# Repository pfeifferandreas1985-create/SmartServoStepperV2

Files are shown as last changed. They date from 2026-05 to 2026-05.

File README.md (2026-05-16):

# 🦾 SmartServoStepperV2

A high-performance Smart Stepper Servo based on the ESP32-C3 Super Mini, TMC2209 driver, and AS5600 magnetic encoder.

## 🚀 Key Features (v3.0.0 Stable)
- **Direct Frequency Positioning:** Oscillation-free, ultra-precise CNC-style open-loop positioning via `FastAccelStepper`.
- **Dual Communication:** Hybrid WiFi (FritzBox Station Mode + Fallback Access Point).
- **Web Dashboard:** Interactive HTML/JS GUI with real-time telemetry (RPS, Angle).
- **Hybrid TMC2209 Control:** Hardware timers for perfect Step/Dir movement, paired with UART for smart driver configuration (SpreadCycle, current limits).

## 📌 Hardware Configuration
| Component | ESP32-C3 GPIO | Function |
| :--- | :--- | :--- |
| UART RX | 5 | Data from TMC2209 |
| UART TX | 6 | Data to TMC2209 |
| ENABLE | 3 | Driver Stage Control |
| STEP | 4 | Hardware Timer Steps |
| DIR | 2 | Hardware Timer Direction |
| I2C SDA | 0 | AS5600 Data |
| I2C SCL | 10 | AS5600 Clock |
| Status LED| 8 | System Heartbeat |

## 📦 Software Setup
1. **Arduino IDE Settings:**
   - Board: `ESP32C3 Dev Module`
   - USB CDC On Boot: **ENABLED** (Required for Serial Monitor)
   - Flash Mode: **DIO**
2. **Libraries Required:**
   - `TMCStepper`
   - `FastAccelStepper`
   - `ArduinoJson (v7)`
   - `WebSocketsServer`
   - `AS5600`
3. **Usage:**
   - Upload `SmartServoStepperV2.ino`.
   - Access the dashboard at `192.168.178.78` (FritzBox) or `192.168.4.1` (AP).

## 🛠 Stability Fixes
- **Startup Delay:** A 3-second delay in `setup()` ensures the USB-CDC port enumerates correctly.
- **Pin Mapping:** Re-routed signals away from sensitive strap pins (GPIO 9) to ensure reliable boots.
- **Encoder Filtering:** 20ms RPS window to prevent aliasing at high speeds.

---
*Maintained by pfeifferandreas1985*

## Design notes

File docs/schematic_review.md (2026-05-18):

# Hardware-Review: Smart Servo Stepper V2 Schaltplan (Phase 2)

**Review-Datum:** 18. Mai 2026  
**Geprüfte Datei:** `/home/ubuntu/Dokumente/output.pdf`  
**Status:** **Teilweise korrigiert – Nahezu produktionsbereit!**

---

## 1. Zusammenfassung der Änderungen (Was wurde korrigiert?)

Der aktualisierte Schaltplan wurde erfolgreich geprüft. Sie haben die kritischsten Stabilitätsprobleme hervorragend gelöst:

*   **TMC Enable Boot-Schutz (Erfolgreich gelöst):** `TMC_EN` (GPIO 3) wird jetzt über den **10 kΩ Widerstand R3** sauber gegen 3.3V gezogen. Der Motor bleibt beim Booten und Flashen absolut still.
*   **Split-UART Schutzwiderstand (Erfolgreich gelöst):** Der **1 kΩ Schutzwiderstand R5** wurde vom RX-Pfad in den TX-Pfad (`TMC_TX` an GPIO 6) verschoben. Damit ist die Kurzschlussgefahr bei Bus-Kollisionen vollständig gebannt!
*   **Symmetrische I2C Pull-Ups (Erfolgreich gelöst):** Sowohl `I2C_SDA` als auch `I2C_SCL` werden jetzt über symmetrische **4.7 kΩ Widerstände** (R2 und R1) versorgt. Das sorgt für saubere Flanken bei 400 kHz (I2C Fast Mode).

---

## 2. Antworten auf Ihre Fragen

### Frage 1: Soll ich SDA von GPIO 0 auf GPIO 20 legen?
> [!IMPORTANT]
> **Ja, absolut!** GPIO 0 ist ein sogenannter **Boot-Strapping-Pin**. Liegt SDA auf GPIO 0 und zieht der AS5600-Encoder die Leitung beim Einschalten auf GND, bootet der ESP32-C3 nicht mehr in Ihre Firmware, sondern bleibt im Download-Modus hängen. 
> 
> Wenn Sie **SDA auf GPIO 20** legen, ist Ihr I2C-Bus wie folgt verdrahtet:
> *   **I2C_SDA:** GPIO 20 (Pin 15) mit 4.7 kΩ Pull-Up gegen 3.3V.
> *   **I2C_SCL:** GPIO 10 (Pin 14) mit 4.7 kΩ Pull-Up gegen 3.3V.
> *   **GPIO 0:** Bleibt komplett unbeschaltet (perfekt für einen sicheren Boot-Vorgang).
> 
> *Hinweis:* Im offiziellen V1.7-Standard des Repositories ist es genau umgekehrt definiert (SDA = GPIO 10, SCL = GPIO 20). Da der ESP32-C3 die Pins jedoch völlig frei konfigurieren kann, ist Ihre Kombination (**SDA = GPIO 20, SCL = GPIO 10**) **technisch absolut gleichwertig und 100% sicher!**

---

### Frage 4: Muss DIAG angeschlossen sein oder kann man diese Funktionen über UART nutzen?
*   **Ja, man kann die StallGuard-Werte (Lasterkennung) über UART auslesen:** Der TMC2209 aktualisiert kontinuierlich das Register `SG_RESULT` (Wert `0` = Blockade). Ihre Firmware kann diesen Wert zyklisch über UART abfragen.
*   **Warum Sie DIAG trotzdem anschließen sollten (Empfehlung):**
    1.  **Latenz (Verzögerung):** Eine UART-Abfrage dauert ca. 1–2 Millisekunden. In dieser Zeit dreht der blockierte Motor weiter und rattert lautstark. Der `DIAG`-Pin ist ein **Hardware-Interrupt**. Er schaltet im selben Mikrosekundenbruchteil auf HIGH, in dem die Blockade auftritt. Der ESP32 kann dadurch sofort stoppen.
    2.  **Bibliotheks-Support:** Fast alle bekannten Bibliotheken (wie `TMCStepper`) nutzen den DIAG-Pin als externen Interrupt für das sensorlose Referenzieren (Sensorless Homing).
*   **Wann Sie DIAG weglassen können:**
    *   Da Sie den **AS5600 Magnet-Encoder** für echtes **Closed-Loop-Control** verbaut haben, benötigen Sie StallGuard für die Positionskontrolle meist gar nicht! Der Encoder erkennt ohnehin sofort jede Abweichung zwischen Soll- und Ist-Position. Wenn Sie kein sensorloses Homing verwenden, sondern normale Endschalter (oder rein über den Encoder referenzieren), kann der DIAG-Pin **problemlos unbeschaltet bleiben**.

---

## 3. Letzte verbleibende Detail-Empfehlungen (Feinschliff)

Falls Sie sich entscheiden, den **DIAG-Pin** für maximale Flexibilität doch anzuschließen, können Sie ein geniales Pin-Mapping-Dominospiel nutzen, das gleichzeitig Pins spart:

```
┌────────────────────────────────────────────────────────┐
│ UART-Pins zusammenführen (Single-Wire)                  │
│ ESP32 GPIO 6 ──► [ 1kΩ Schutz ] ──┬──► TMC2209 PDN     │
│                                   └──► 4.7kΩ Pull-Up   │
└────────────────────────────────────────────────────────┘
```

1.  **UART auf einen Pin reduzieren:** Da der ESP32-C3 hardwareseitig echten Eindraht-UART (Half-Duplex) unterstützt, können Sie `TMC_TX` und `TMC_RX` auf dem ESP32-Pin **GPIO 6** zusammenführen (über den 1 kΩ Serienwiderstand).
2.  **GPIO 5 freigeben:** Dadurch wird **GPIO 5** (der bisherige `TMC_RX`) frei!
3.  **TMC_DIR verschieben:** Legen Sie `TMC_DIR` von GPIO 2 auf den frei gewordenen **GPIO 5** (entspricht exakt der V1.7 Spezifikation).
4.  **GPIO 2 für DIAG nutzen:** Nun ist **GPIO 2** frei und Sie können den `DIAG`-Pin des TMC2209 dorthin verkabeln (mit einem 4.7 kΩ Pull-Up gegen 3.3V).

Mit diesem Kniff haben Sie **DIAG voll funktionsfähig angeschlossen**, ohne einen einzigen zusätzlichen Pin des ESP32-C3 Super Mini zu verschwenden!

---

## 4. Fazit der Freigabe

*   Wenn Sie **SDA auf GPIO 20** verschieben und die DIAG-Funktion nicht zwingend über einen Hardware-Interrupt benötigen: **Der Schaltplan ist hiermit FREIGEGEBEN für das PCB-Layout!**
*   Wenn Sie die DIAG-Interrupt-Funktion nutzen möchten: Setzen Sie das unter Abschnitt 3 beschriebene Pin-Dominospiel um. Danach ist der Plan ebenfalls **FREIGEGEBEN**.

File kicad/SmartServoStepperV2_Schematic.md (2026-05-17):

# SmartServoStepperV2 – Konsistenter KiCad-Stromlaufplan

**für ESP32-C3 Super Mini + TMC2209 Tenstar Robot V2 + AS5600**

> Verifiziert gegen Firmware `SmartServoStepperV2.ino` (Stand: Mai 2026)

---

## 1. Power Architecture

### VMOT Eingang (12–24V)

```text
VIN_MOTOR ────────────────+─────────────> VMOT (TMC2209)
                          |
                          |
                       [SMBJ24A]
                          |
                         GND

VIN_MOTOR ──────+────────────+
                |            |
              [470µF]      [100nF]
                |            |
               GND          GND
```

### Buck Converter (MP1584EN)

```text
VIN_MOTOR ─────────> MP1584EN IN+

GND ───────────────> MP1584EN IN-

MP1584 OUT+ ───────> +5V_SYS
MP1584 OUT- ───────> GND
```

### 5V Ausgangspufferung

```text
+5V_SYS ──────+────────+────────+
              |        |        |
            [100µF] [47µF] [100nF]
              |        |        |
             GND      GND      GND
```

---

## 2. ESP32-C3 Super Mini Versorgung

```text
+5V_SYS ─────────────> ESP32 5V
GND ─────────────────> ESP32 GND
```

---

## 3. 3.3V Logic Rail

```text
ESP32 3V3 ───────────> +3V3_LOGIC
```

**Verbraucher:**
- AS5600 VCC
- TMC2209 VIO
- I2C Pullups
- UART Pullup
- ENABLE Pullup

---

## 4. AS5600 Encoder

### Versorgung

```text
+3V3_LOGIC ───────> AS5600 VCC
GND ──────────────> AS5600 GND

+3V3_LOGIC ──[10µF]── GND
```

### I2C

```text
ESP32 GPIO0  ─────────────> SDA
                     |
                   [4.7k]
                     |
                  +3V3

ESP32 GPIO10 ────────────> SCL
                     |
                   [4.7k]
                     |
                  +3V3
```

---

## 5. TMC2209 Tenstar V2

### Versorgung

```text
VMOT  ─────────────> VM
GND   ─────────────> GND

+3V3_LOGIC ────────> VIO
```

### STEP / DIR

```text
ESP32 GPIO4 ───────> STEP

ESP32 GPIO2 ───────> DIR
```

### ENABLE (Boot-Safe)

```text
ESP32 GPIO3 ───────> EN

EN ─────[10k]──────> +3V3
```

> Damit bleibt der Treiber beim Boot deaktiviert.

---

## 6. UART Verbindung (WICHTIG)

Beim Tenstar TMC2209 V2 wird UART über PDN_UART geführt.

### Verschaltung

```text
ESP32 GPIO5 (RX) ───────────────┐
                                │
                                ├────> PDN_UART
                                │
ESP32 GPIO6 (TX) ──[1k]─────────┘

PDN_UART ──[4.7k]──> +3V3
```

> **Hinweis:** Der 1kΩ Serienwiderstand sitzt am **TX-Pin (GPIO 6)**, damit bei der Two-Wire-Konfiguration der TMC2209 den Bus beim Antworten übersteuern kann.

---

## 7. Feetech Half-Duplex Bus (1 Mbps)

**Verwendet:**
- GPIO1 = TX
- GPIO7 = RX
- BSS138 Bidirectional Level Shifter

---

## 8. Level Shifter Verschaltung

### LV-Seite (3.3V)

```text
ESP32 GPIO1 ──[220R]──> LV1

ESP32 GPIO7 ──────────> LV2

LV ───────────────────> +3V3
GND ──────────────────> GND
```

### HV-Seite (5V)

```text
HV1 ───────┐
           ├──────> FEETECH_DATA
HV2 ───────┘

HV ────────────────> +5V_SYS

FEETECH_DATA ──[2.2k]──> +5V_SYS
```

---

## 9. Motoranschlüsse

```text
TMC2209 A1 ─────> MOTOR_A+
TMC2209 A2 ─────> MOTOR_A-

TMC2209 B1 ─────> MOTOR_B+
TMC2209 B2 ─────> MOTOR_B-
```

---

## 10. USB / JTAG

```text
GPIO18 → NC
GPIO19 → NC
```

> **Nicht verbinden.**

---

## 11. Empfohlene KiCad-Netlabels

### Power

| Label | Beschreibung |
| :--- | :--- |
| `VIN_MOTOR` | Eingangsversorgung 12–24V |
| `+5V_SYS` | Buck-Converter Ausgang |
| `+3V3_LOGIC` | ESP32 3.3V Rail |
| `GND` | Masse |
| `VMOT` | TMC2209 Motor-Versorgung |

### Motor

| Label | Beschreibung |
| :--- | :--- |
| `MOTOR_A+` | Spule A+ |
| `MOTOR_A-` | Spule A- |
| `MOTOR_B+` | Spule B+ |
| `MOTOR_B-` | Spule B- |

### I2C

| Label | Beschreibung |
| :--- | :--- |
| `I2C_SDA` | GPIO0 |
| `I2C_SCL` | GPIO10 |

### TMC

| Label | Beschreibung |
| :--- | :--- |
| `TMC_STEP` | GPIO4 |
| `TMC_DIR` | GPIO2 |
| `TMC_EN` | GPIO3 |
| `TMC_UART` | PDN_UART (GPIO5 + GPIO6) |

### Feetech

| Label | Beschreibung |
| :--- | :--- |
| `FEETECH_TX` | GPIO1 |
| `FEETECH_RX` | GPIO7 |
| `FEETECH_DATA` | 5V Bus (1-Wire) |

---

## 12. Kritische Layoutregeln

### TMC2209

- 470µF Elko **maximal 15 mm** vom VM-Pin entfernt
- Breite VMOT-Polygonfläche
- **Thermal-Vias** unter Exposed Pad:
  - Mindestens **5 Stück**
  - **0.3 mm** Drill
  - Via-in-pad optional

### I2C

- SDA/SCL **kurz** halten
- **Nicht** parallel zu Motorphasen

### UART

- PDN_UART **kurz** routen
- **Keine** Nähe zu STEP-Leitung

### Motorphasen

- A/B **differenziell und symmetrisch**
- Möglichst **breite Leiterbahnen**

---

## 13. ERC-kritische Hinweise

> **WICHTIG:** Der ESP32-C3 besitzt einige Boot-Strapping-Pins.

Die gewählte Belegung ist gültig, weil:

- **GPIO3** durch Pull-Up definiert
- **GPIO0** nur via I2C Pull-Up belastet
- **GPIO1** TX nur über 220R gekoppelt
- **GPIO18/19** unbenutzt

**Damit ist das Design bootfähig.**

---

## 14. Empfohlene KiCad-Hierarchie

```text
ROOT
├── Power.kicad_sch
├── ESP32.kicad_sch
├── TMC2209.kicad_sch
├── AS5600.kicad_sch
├── FeetechBus.kicad_sch
└── Connectors.kicad_sch
```

---

## 15. Footprint-Empfehlungen

### Passiv

| Typ | Footprint |
| :--- | :--- |
| 100nF | 0603 |
| 4.7kΩ | 0603 |
| 220Ω | 0603 |
| 1kΩ | 0603 |
| 2.2kΩ | 0603 |
| 10kΩ | 0603 |
| 10µF | 0805 |
| 47µF X7R | 1206 |
| 470µF Elko | Radial D10 |

---

## 16. Wichtigste elektrische Freigabe

Dieses Design ist konsistent bezüglich:

- ✅ Power Domains
- ✅ Boot-Verhalten
- ✅ UART (TMC2209 Two-Wire)
- ✅ I2C (AS5600)
- ✅ Half-Duplex Bus (Feetech via BSS138)
- ✅ ESP32-C3 Bootstrapping
- ✅ 3.3V / 5V Pegel
- ✅ EMV-Basismaßnahmen

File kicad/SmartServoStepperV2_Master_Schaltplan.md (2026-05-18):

# SmartServoStepperV2 – PCB Wiring & Schaltplan (v2.2 Verified)

Dieses Dokument ist der **Master-Bauplan** für das PCB-Layout, optimiert für den Einsatz von fertigen Modulen (ESP32-C3 Super Mini + Tenstar TMC2209 V2) und externen Anschlüssen über Dupont-Steckverbinder.

---

## 1. Systemarchitektur & Power Grid

### VMOT (12V–24V) – Haupteinspeisung über Stecker [J1]

- **Quelle:** Pin 1 von Stecker J1 (3-pol. Dupont).
- **Schutz:** SMBJ24A TVS-Diode (transiente Überspannungen) + 100nF Keramik (HF-Filter) direkt hinter dem Stecker-Pin gegen GND.
- **Pufferung:** 470 µF / 50V Elko (Low-ESR) unmittelbar an den VM / GND Pins der Tenstar-Modul-Stiftleiste.

### 5V System (SYS) – Logik-Hauptstromkreis

- **Quelle:** MP1584EN Buck-Converter (Ausgang lokal gepuffert mit 22µF Keramik).
- **MCU-Pufferung:** 100 µF Elko + 47 µF Keramik (X7R, 1206) + 100 nF Keramik parallel geschaltet, so nah wie möglich am 5V-Pin des ESP32-C3 Super Mini Moduls.
- **Bus-Speisung:** Dient als Pull-Up-Quelle für die 5V-Busseite (1-Wire TTL).

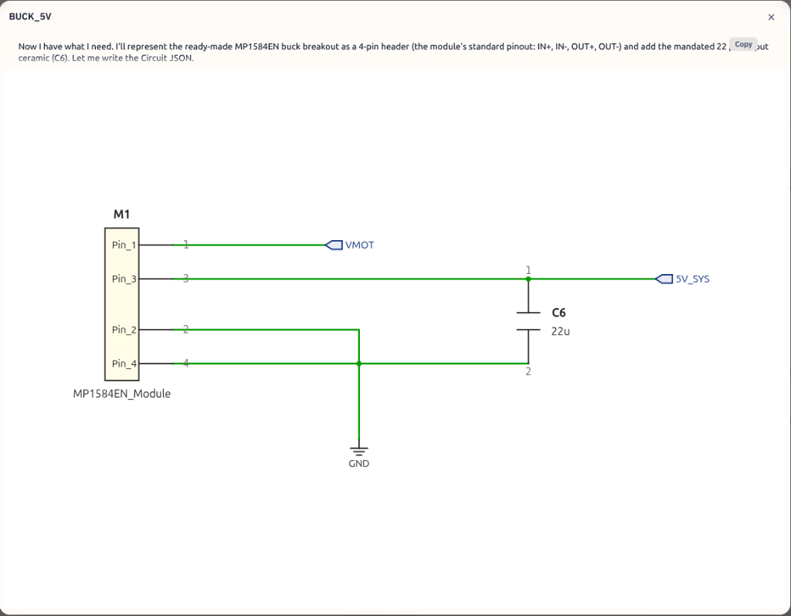
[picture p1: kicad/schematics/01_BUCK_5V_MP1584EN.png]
MP1584EN Buck Converter 5V Schaltplan


### 3.3V Logik (LOGIC) – Signalstromkreis

- **Quelle:** Interner Spannungsregler des ESP32-C3 Super Mini (wird am 3V3-Pin des Moduls abgegriffen).
- **TMC2209 VIO:** Zwingend mit dieser 3.3V-Schiene verbinden.
- **Sensor-Speisung:** Wird direkt an Pin 1 des AS5600-Steckers J2 geführt.

---

## 2. Externe Steckverbinder (Interfaces)

### J1: Hauptanschluss (3-poliger Dupont-Stecker)

Dieser Stecker führt die Spannungsversorgung zu und bindet die Platine an den externen Feetech 1-Wire TTL Bus an.

| Pin | Signal | Beschreibung |
| :--- | :--- | :--- |
| **Pin 1** | `VMOT` | 12V–24V Eingang |
| **Pin 2** | `GND` | Gemeinsame Systemmasse |
| **Pin 3** | `FT_DATA` | 5V 1-Wire TTL Busleitung |

### J2: AS5600 Encoder-Anschluss (4-poliger Dupont-Stecker)

Über diesen Stecker wird das extern sitzende AS5600-Sensor-Modul ausgelesen.

| Pin | Signal | Beschreibung |
| :--- | :--- | :--- |
| **Pin 1** | `3V3_LOGIC` | Spannungsversorgung für den Sensor |
| **Pin 2** | `GND` | Masse |
| **Pin 3** | `I2C_SDA` | I2C Datenleitung, mit 4.7kΩ Pull-Up auf dem Mainboard |
| **Pin 4** | `I2C_SCL` | I2C Taktleitung, mit 4.7kΩ Pull-Up auf dem Mainboard |

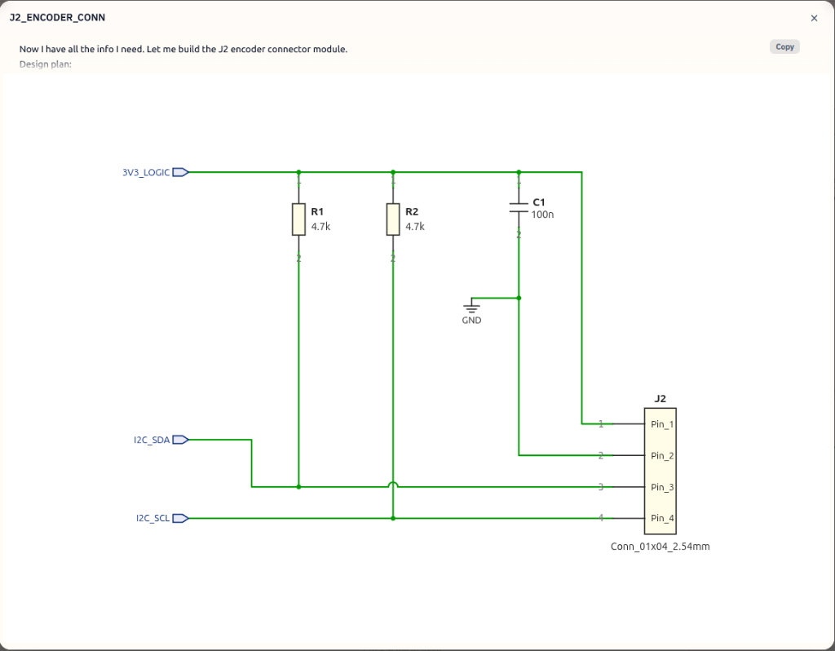
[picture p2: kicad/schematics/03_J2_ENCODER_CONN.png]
J2 Encoder Connector Schaltplan


---

## 3. Finales Pin-Mapping (ESP32-C3 Super Mini Modul)

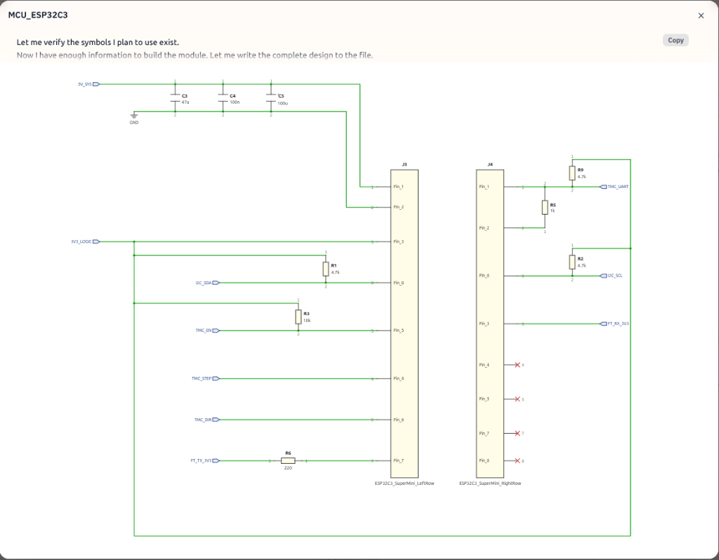
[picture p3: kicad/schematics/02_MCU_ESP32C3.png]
MCU ESP32-C3 Super Mini Schaltplan


| Modul Pin | Funktion | Beschreibung | Hardware-Beschaltung auf dem Mainboard |
| :--- | :--- | :--- | :--- |
| **5V** | `5V_SYS` | Moduleingang 5V | MP1584EN Ausgang / Bulk-Kondensatoren (C3, C4, C5) |
| **3V3** | `3V3_LOGIC` | Modulausgang 3.3V | Speist VIO (TMC), Stecker J2 Pin 1, Level Shifter & Pull-Ups |
| **GND** | `GND` | Systemmasse | Verbunden mit der zentralen Massefläche (Ground Plane) |
| **GPIO 0** | *Unbeschaltet* | Boot-Strap-Pin | **Zwingend offen lassen**, um Boot-Konflikte der MCU zu verhindern! |
| **GPIO 1** | `FT_TX` | Bus Senden | Über R6 (220Ω) Serienwiderstand → BSS138 Source 1 |
| **GPIO 2** | `TMC_DIR` | Richtungs-Signal | Direkt an Tenstar TMC2209 Pin: DIR |
| **GPIO 3** | `TMC_EN` | TMC2209 EN (Active LOW) | R3 (10kΩ) Pull-UP gegen 3V3_LOGIC → Tenstar Pin: EN |
| **GPIO 4** | `TMC_STEP` | Schritt-Impuls | Direkt an Tenstar TMC2209 Pin: STEP |
| **GPIO 5** | `TMC_RX` | UART Rx | Direkt an Netzknoten TMC_UART_NODE |
| **GPIO 6** | `TMC_TX` | UART Tx | R5 (1kΩ) Schutzwiderstand in Serie zu TMC_UART_NODE |
| **GPIO 7** | `FT_RX` | Bus Empfangen | Direkt → BSS138 Source 2 |
| **GPIO 8** | Status-LED | On-Board LED (Blau) | Modulintern verschaltet (Active LOW) |
| **GPIO 10** | `I2C_SCL` | I2C Takt (AS5600) | R2 (4.7kΩ) Pull-UP gegen 3V3_LOGIC → Stecker J2 Pin 4 |
| **GPIO 18** | USB D- | Intern reserviert | **Physisch unbeschaltet lassen!** (Verhindert USB-JTAG Störungen) |
| **GPIO 19** | USB D+ | Intern reserviert | **Physisch unbeschaltet lassen!** (Verhindert USB-JTAG Störungen) |
| **GPIO 20** | `I2C_SDA` | I2C Daten (AS5600) | R1 (4.7kΩ) Pull-UP gegen 3V3_LOGIC → Stecker J2 Pin 3 |

---

## 4. Spezifische Schaltungsdetails

### 4.1 Feetech-Bus High-Speed Level Shifter (3.3V ↔ 5V Eindraht)

Die TX/RX-Pfade des ESP32 werden zusammengeführt und auf die 5V-Ebene angehoben, um am Stecker J1 als echtes Eindraht-TTL-Signal anzuliegen.

```text
ESP32-C3 Modul Pins                                       Hauptstecker J1
───────────────────                                       ───────────────
GPIO 1 (TX) ──→ [ R6: 220Ω ] ──→ BSS138 (Source 1) ──┐
                                                     ├───► Pin 3: DATA (1-Wire)
GPIO 7 (RX) ───────────────────→ BSS138 (Source 2) ──┘
                                                     │
                                               [ R8: 2.2kΩ Pull-Up ] → 5V_SYS
```

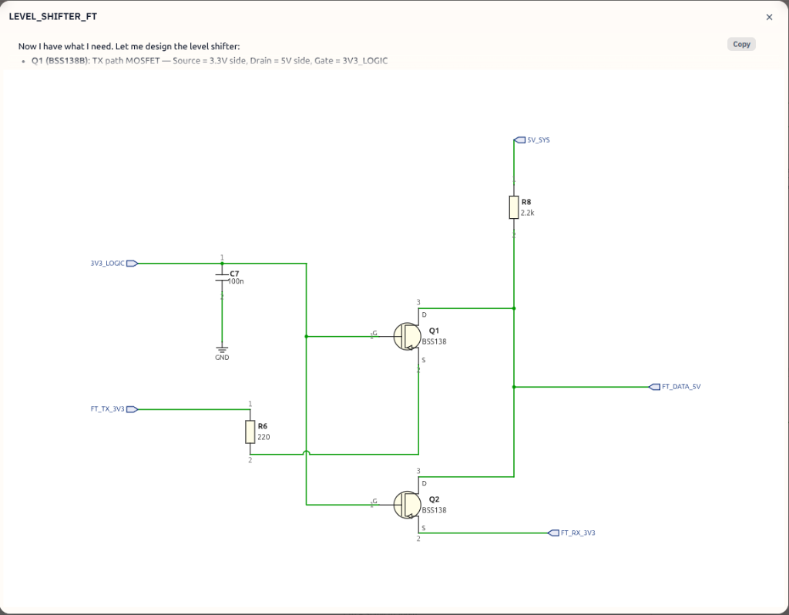
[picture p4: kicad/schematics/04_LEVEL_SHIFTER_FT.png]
Feetech-Bus Level Shifter Schaltplan


### 4.2 TMC2209 UART (Two-Wire to One-Wire Konfiguration)

```text
ESP32-C3 GPIO 5 (RX) ───────────────────────────┬───► [ Tenstar Modul Pin: PDN_UART ]
                                                │
ESP32-C3 GPIO 6 (TX) ─── [ R5: 1 kΩ Serie ] ────┤
                                                │
3V3_LOGIC ────────────── [ R9: 4.7 kΩ Pull-Up ] ┘
```

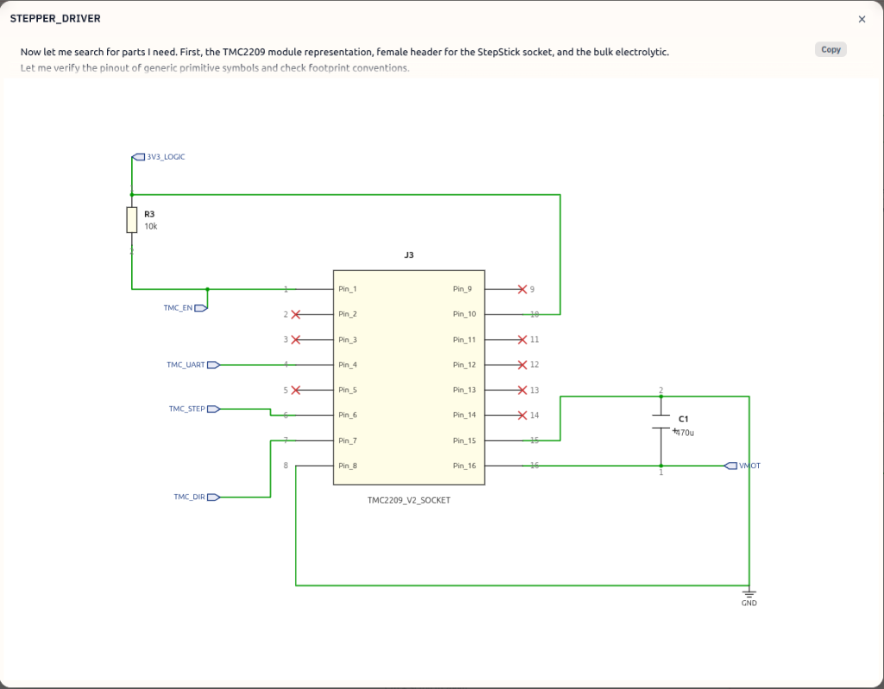
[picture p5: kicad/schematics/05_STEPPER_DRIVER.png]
Stepper Driver TMC2209 Schaltplan


---

## 5. Stückliste (BOM)

### Aktive Bauteile & Module

| Typ | Bauteil / Modul | Menge | Funktion |
| :--- | :--- | :--- | :--- |
| **MCU** | ESP32-C3 Super Mini Modul | 1x | Hauptprozessor |
| **Driver** | Tenstar TMC2209 V2 Modul | 1x | Schrittmotortreiber (StepStick) |
| **Comms** | BSS138 Transistor / Modul | 2x / 1x | Pegelwandler für den Feetech-Bus |
| **Power** | MP1584EN Buck Converter Modul | 1x | Step-Down-Regler (12V/24V → 5V) |
| **Schutz** | SMBJ24A TVS-Diode | 1x | Transientenschutz an der Stromeinspeisung |

### Passivbauteile & Verbinder

| ID | Bauteiltyp | Wert / Typ | Platzierung / Funktion |
| :--- | :--- | :--- | :--- |
| J1 | Dupont-Stiftleiste | 3-polig, gerade/gewinkelt | Hauptanschluss: 12V-24V IN / GND / 1-Wire DATA |
| J2 | Dupont-Stiftleiste | 4-polig, gerade/gewinkelt | Externer Encoder-Anschluss: 3V3 / GND / SDA / SCL |
| C1 | Elko (Low-ESR, ≥ 50V) | 470 µF | Direkt an den Pins VM / GND der Tenstar-Stiftleiste |
| C2 | Keramik-Kondensator | 100 nF | Direkt an Stecker J1 (Pin 1 / Pin 2) parallel zur TVS-Diode |
| C3 | Keramik (X7R, 1206) | 47 µF | Direkt am Pin 5V der ESP32-Stiftleiste |
| C4 | Keramik-Kondensator | 100 nF | Entkopplung, parallel zu C3 am ESP32 5V Pin |
| C5 | Elko (≥ 10V) | 100 µF | Bulk-Puffer, parallel zu C3/C4 am ESP32 5V Pin |
| C6 | Keramik-Kondensator | 22 µF | Direkt am Ausgang (OUT+) des MP1584EN Moduls |
| R1 | Widerstand | 4.7 kΩ | Pull-Up: I2C_SDA → 3V3_LOGIC (nahe Stecker J2) |
| R2 | Widerstand | 4.7 kΩ | Pull-Up: I2C_SCL → 3V3_LOGIC (nahe Stecker J2) |
| R3 | Widerstand | 10 kΩ | Boot-Safe Pull-Up: Tenstar Pin EN → 3V3_LOGIC |
| R5 | Widerstand | 1 kΩ | Schutzwiderstand: ESP32 GPIO 6 (TX) → TMC_UART_NODE |
| R6 | Widerstand | 220 Ω | Schutzwiderstand: ESP32 GPIO 1 (TX) → BSS138 Source 1 |
| R8 | Widerstand | 2.2 kΩ | Bus-Terminierung: J1 Pin 3 (DATA) → 5V_SYS |
| R9 | Widerstand | 4.7 kΩ | Bus-Pull-Up: TMC_UART_NODE → 3V3_LOGIC |

---

## 6. Layout-Hinweise für diese Revision

- **Leistungsführung (VMOT/GND):** Die Leiterbahn von J1 Pin 1 (VMOT) zu TMC2209 VM sowie von J1 Pin 2 (GND) zu TMC2209 GND muss die breiteste Verbindung auf der Platine sein, da hier der volle Motorstrom fließt (siehe Detailtabelle unten).

- **I2C-Leitungen schützen:** Die Leitungen von GPIO 20 und GPIO 10 zum Stecker J2 sollten parallel und nah beieinander geführt werden. Halte sie fern von den Motor-Ausgangsleitungen (Pins 1A, 1B, 2A, 2B des Treibers), um induktive Störungen auf dem I2C-Bus zu vermeiden.

- **Kondensatoren-Platzierung:** C3, C4, C5 gehören im Layout direkt an den 5V-Pin des ESP32-Moduls, nicht an den Ausgang des Buck-Converters. C1 gehört direkt an den VM-Pin des Treiber-Moduls.

---

## 7. Leiterplatten-Designregeln & Leiterbahnbreiten (IPC-2152)

Um eine minimale Erwärmung (max. ΔT = 10°C) bei einer standardmäßigen Kupferauflage von **35 µm (1 oz)** zu gewährleisten, müssen für das PCB-Layout in KiCad die folgenden **Netzklassen (Net Classes)** definiert und angewendet werden.

### 7.1 Spezifikation der Netzklassen für KiCad

| Netzklasse (KiCad Name) | Zugehörige Netze (Net Names) | Max. Strom | Empf. Breite (External) | Empf. Breite (Internal) | Clearance (Abstand) |
| :--- | :--- | :---: | :---: | :---: | :---: |
| **Power_High** | `+12V`, `/M1A`, `/M1B`, `/M2A`, `/M2B` | **2,5 A** | **1,0 mm** (~40 mil) | **1,5 mm** (~60 mil) | **0,3 mm** (~12 mil) |
| **Power_Medium** | `+5V`, `/5V` | **1,0 A** | **0,4 mm** (~16 mil) | **0,6 mm** (~24 mil) | **0,2 mm** (~8 mil) |
| **Power_Logic** | `+3.3V`, `+3V3` | **0,2 A** | **0,25 mm** (~10 mil) | **0,35 mm** (~14 mil) | **0,2 mm** (~8 mil) |
| **Signal_Standard** | `/Step`, `/Dir`, `/UART`, `FT_TX`, `FT_RX`, `/Diag` | **< 10 mA**| **0,2 mm** (~8 mil) | **0,2 mm** (~8 mil) | **0,2 mm** (~8 mil) |
| **Signal_I2C** | `/SDA`, `/SCL` | **< 5 mA** | **0,2 mm** (~8 mil) | **0,2 mm** (~8 mil) | **0,25 mm** (~10 mil) |
| **Feetech_DATA** | `/TTL_1_Wire` | **0,5 A** | **0,3 mm** (~12 mil) | **0,4 mm** (~16 mil) | **0,25 mm** (~10 mil) |

> [!TIP]
> **Masseführung (GND):** Verwenden Sie für **GND** keine dünnen Leiterbahnen! Legen Sie auf der Unterseite der Platine (`B.Cu`) eine **durchgehende Kupfer-Massefläche (GND Ground Plane)** an. Alle GND-Pins werden über *Thermal Reliefs* direkt an diese Fläche angebunden. Das minimiert EMI-Störungen, verbessert das thermische Verhalten des TMC2209 massiv und senkt die Impedanz.

### 7.2 Technische Berechnungsbasis (IPC-2152)

*   **Motorstrom-Leitungen (Power_High):** 
    Bei $2,5\text{ A}$ Stromstärke erfordert die thermische Stabilität eine Mindest-Querschnittsfläche des Kupfers. Bei 35 µm Kupferdicke führt eine **1,0 mm breite Außenleiterbahn** zu einer Erwärmung von unter 10°C über Umgebungstemperatur. 
*   **Hilfsspannungen (Power_Medium):** 
    Die 5V-Leitung speist unter anderem den Feetech-Bus. Um Spannungsabfälle bei Busaktivität zu minimieren, wird sie auf **0,4 mm** dimensioniert.
*   **Signalschutz (Signal_I2C):** 
    Für I2C-Leitungen (`SDA` / `SCL`) wird ein erhöhter Mindestabstand (Clearance) von **0,25 mm** empfohlen, um kapazitives Übersprechen von den Step/Dir-Leitungen zu verhindern.

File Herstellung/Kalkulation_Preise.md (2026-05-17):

# SmartServoStepperV2 – Herstellungskosten & Preiskalkulation

Dieses Dokument bietet eine vollständige Übersicht über die Herstellungskosten und das Projekt-Budget für den **SmartServoStepperV2** in verschiedenen Produktions-Staffelungen (10x, 100x, 1000x) sowie einen Vergleich zwischen dem Bezug aus China und Deutschland.

---

## 1. Einzelkomponenten-Preise (Übersicht pro Stück)

Hier siehst du, wie sich der Stückpreis der einzelnen Komponenten je nach Bestellmenge und Einkaufsquelle verändert.

### Bezug aus China (Aliexpress / LCSC / JLCPCB) – Preise pro Stück

| Komponente | Stückpreis bei 10x | Stückpreis bei 100x | Stückpreis bei 1000x |
| :--- | :--- | :--- | :--- |
| **ESP32-C3 Super Mini** | ~2,50 € | ~1,80 € | ~1,30 € |
| **Tenstar TMC2209 V2** | ~2,20 € | ~1,60 € | ~1,10 € |
| **MP1584EN Buck Modul** | ~0,80 € | ~0,50 € | ~0,35 € |
| **BSS138 Level Shifter Mosfets** | ~0,10 € | ~0,03 € | ~0,01 € |
| **Passiva & Schutz** (Kondensatoren, TVS, Widerstände, Stecker) | ~0,60 € (Set) | ~0,25 € | ~0,08 € |
| **Leiterplatte (PCB)** (z. B. JLCPCB) | ~1,50 € | ~0,40 € | ~0,15 € |
| **Gesamtkosten pro Stück (China)** | **~7,70 €** | **~4,58 €** | **~2,99 €** |

### Bezug aus Deutschland (Amazon / Reichelt / Conrad) – Preise pro Stück

| Komponente | Stückpreis bei 10x | Stückpreis bei 100x | Stückpreis bei 1000x |
| :--- | :--- | :--- | :--- |
| **ESP32-C3 Super Mini** | ~6,00 € | ~4,50 € | ~3,50 € |
| **Tenstar TMC2209 V2** | ~5,50 € | ~4,00 € | ~3,00 € |
| **MP1584EN Buck Modul** | ~2,50 € | ~1,80 € | ~1,20 € |
| **BSS138 Level Shifter Mosfets** | ~0,40 € | ~0,15 € | ~0,08 € |
| **Passiva & Schutz** (Kondensatoren, TVS, Widerstände, Stecker) | ~1,50 € (Set) | ~0,60 € | ~0,25 € |
| **Leiterplatte (PCB)** (DE-Express/EU) | ~4,50 € | ~1,50 € | ~0,75 € |
| **Gesamtkosten pro Stück (DE)** | **~20,40 €** | **~12,55 €** | **~8,78 €** |

---

## 2. Gesamtkosten nach Projekt-Staffelung (Projekt-Budget)

Hier sind die hochgerechneten Gesamtkosten für die jeweilige Gesamtbestellung (reine Materialkosten inkl. geschätztem Versand).

### 📊 Staffelvergleich im Überblick

| Staffel | Bezug China (Aliexpress/PCBA) | Bezug Deutschland (Amazon/Distributoren) | Hauptfokus / Charakteristik |
| :--- | :--- | :--- | :--- |
| **10x** | **~85 € bis 100 €** | **~220 € bis 250 €** | Prototyping & Entwicklung |
| **100x** | **~450 € bis 500 €** | **~1.250 € bis 1.400 €** | Kleinserie & Vorserie |
| **1000x** | **~2.800 € bis 3.200 €** | **~8.500 € bis 9.500 €** | Industrielle Produktion (PCBA) |

---

### 🔹 Staffelung 10x (Kleinserie / Prototyping)

*   **Bezug China (Aliexpress):** **~85 € bis 100 €**
    > *Hinweis:* PCBs kosten in China für 5–10 Stück pauschal nur ca. 2–5 $ (zzgl. Versand). Die Bauteile werden in Mindestmengen (oft 5er- oder 10er-Packs) gekauft.
*   **Bezug Deutschland (Amazon/Reichelt):** **~220 € bis 250 €**
    > *Hinweis:* Auf Amazon zahlt man für Modul-Mehrfachpacks (z. B. 3er-Pack ESP32) deutlich mehr, hat es aber in 24 Stunden da.

### 🔹 Staffelung 100x (Kleinserie)

*   **Bezug China (Aliexpress/LCSC):** **~450 € bis 500 €**
    > *Hinweis:* Hier greifen bereits echte Rabatte. Die PCBs kosten kaum noch etwas im Verhältnis. Der Versand fällt kaum ins Gewicht.
*   **Bezug Deutschland (Amazon/Distributoren):** **~1.250 € bis 1.400 €**
    > *Hinweis:* Amazon ist hierfür der falsche Ort (zu teuer). Man müsste über gewerbliche Distributoren (wie Bürklin, Rutronik oder Mouser DE) einkaufen, um diese Preise zu halten.

### 🔹 Staffelung 1000x (Industrielle Menge)

*   **Bezug China (Großhandel/Direct Sourcing):** **~2.800 € bis 3.200 €**
    > *Hinweis:* Bei dieser Menge kauft man keine "Module" mehr auf Aliexpress, sondern lässt die Platinen direkt in China (z. B. bei JLCPCB oder PCBWay) vollbestückt (PCBA) herstellen. Das ist oft günstiger, als die Module einzeln per Hand aufzulöten.
*   **Bezug Deutschland (Großhandel):** **~8.500 € bis 9.500 €**
    > *Hinweis:* Einkauf über offizielle deutsche Distributoren mit Mengenrabattstaffel und ggf. Zollabwicklung inklusive.

---

## 3. Wichtige Insider-Tipps für deine Kalkulation

> [!TIP]
> **Der PCBA-Faktor (Bestückung in China)**
> Da du Standardmodule (TMC2209 und ESP32) verwendest, schau dir bei einer 100er- oder 1000er-Staffel die Bestückungskosten (PCBA) von chinesischen Werken an. Es ist oft billiger, wenn das Werk die SMD-Kleinteile (Widerstände, Kondensatoren, TVS-Diode, Level Shifter) direkt maschinell auflötet. Du musst dann nur noch die zwei großen Module per Hand einstecken/einlöten.

> [!IMPORTANT]
> **Zoll & Einfuhrumsatzsteuer**
> Bei Bezug aus China fallen ab 150 € Warenwert Zollgebühren an (Einfuhrumsatzsteuer von 19 % wird bei Aliexpress meist direkt an der Kasse berechnet). Das ist in den obigen Gesamtkosten grob einkalkuliert.

> [!WARNING]
> **Qualitätsrisiko bei China-Modulen**
> Bei 1000 Stück TMC2209-Modulen aus extrem billigen China-Quellen musst du mit einer Ausschussrate von ca. **2–5 %** rechnen (Treiber, die defekt ankommen oder beim ersten Einschalten sterben). Plane dies unbedingt als Puffer ein.

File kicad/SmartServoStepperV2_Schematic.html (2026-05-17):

# SmartServoStepperV2

Vollständiger KiCad-Schaltplan

ESP32-C3 Super Mini TMC2209 Tenstar V2 AS5600 Encoder MP1584EN Buck BSS138 Level Shifter

## 1. Systemübersicht

Versorgung | Spannung | Zweck
VMOT | 12V – 24V | Motorversorgung TMC2209
+5V_SYS | 5V | ESP32, Level Shifter HV
+3V3_LOGIC | 3.3V | AS5600, TMC VIO, Pullups

## 2. Haupt-Netze

Netzname | Funktion
VIN_MOTOR | 12–24V Eingang
VMOT | Motorversorgung TMC2209
+5V_SYS | 5V Versorgung
+3V3_LOGIC | 3.3V Logik
GND | Masse
TMC_UART | UART Verbindung TMC
I2C_SDA | I2C Daten
I2C_SCL | I2C Clock
FEETECH_DATA | Half Duplex Servo Bus

## 3. Versorgungsschaltung

### Eingangsschutz

D1 – SMBJ24A TVS-Diode

Kathode → VIN_MOTOR Anode → GND

C1 – 470µF / 50V Low ESR

Plus → VIN_MOTOR Minus → GND

C2 – 100nF Keramik

VIN_MOTOR → GND

## 4. Buck Converter

U4 – MP1584EN

### Eingang

IN+ → VIN_MOTOR IN− → GND

### Ausgang

OUT+ → +5V_SYS OUT− → GND

C6 – 22µF Keramik

+5V_SYS → GND

MP1584EN Buck Converter 5V Schaltplan

## 5. ESP32-C3 Super Mini

U1 – ESP32-C3 Super Mini

### Versorgung

ESP32 Pin | Verbindung
5V | +5V_SYS
GND | GND
3V3 | +3V3_LOGIC

### GPIO Belegung

GPIO 0I2C SDA

GPIO 1Feetech TX

GPIO 2TMC DIR

GPIO 3TMC ENABLE

GPIO 4TMC STEP

GPIO 5TMC UART RX

GPIO 6TMC UART TX

GPIO 7Feetech RX

GPIO 8Status LED

GPIO 10I2C SCL

GPIO 18NC

GPIO 19NC

MCU ESP32-C3 Super Mini Schaltplan

## 6. ESP32 Versorgungspufferung

Bauteil | Wert | Anschluss
C3 | 47µF X7R 1206 | +5V_SYS → GND
C4 | 100nF | +5V_SYS → GND
C5 | 100µF | +5V_SYS → GND

Hinweis: Alle drei Kondensatoren möglichst nahe am ESP32 platzieren.

## 7. AS5600 Encoder

U3 – AS5600

### Versorgung

Pin | Verbindung
VCC | +3V3_LOGIC
GND | GND

### I2C

Pin | Verbindung
SDA | GPIO 0
SCL | GPIO 10

### Pullups & Pufferung

Bauteil | Wert | Anschluss
R1 | 4.7kΩ | SDA → +3V3_LOGIC
R2 | 4.7kΩ | SCL → +3V3_LOGIC
C7 | 10µF Keramik | +3V3_LOGIC → GND

J2 Encoder Connector Schaltplan

## 8. TMC2209 Tenstar Modul V2

U2 – TMC2209

### Versorgung

Pin | Verbindung
VM | VMOT
GND | GND
VIO | +3V3_LOGIC

### STEP / DIR

Pin | Verbindung
STEP | GPIO 4
DIR | GPIO 2

### ENABLE (Boot-Safe)

Pin | Verbindung
EN | GPIO 3

R3 – 10kΩ Pullup: EN → +3V3_LOGIC

Hinweis: Dadurch bleibt der Treiber beim Boot deaktiviert.

### UART (TMC_UART Netz)

ESP32 GPIO5 (RX) ───────────────┐ │ ├────> PDN_UART │ ESP32 GPIO6 (TX) ──[1kΩ]────────┘ PDN_UART ──[4.7kΩ]──> +3V3_LOGIC

Bauteil | Wert | Anschluss
R5 | 1kΩ | GPIO 6 → PDN_UART
R9 | 4.7kΩ | PDN_UART → +3V3_LOGIC

Stepper Driver TMC2209 Schaltplan

## 9. Motoranschluss

J2 – Stepper Connector

Pin | Verbindung
1 | A1
2 | A2
3 | B1
4 | B2

## 10. Feetech Half Duplex Bus

U5 – BSS138 Level Shifter

### LV-Seite (3.3V)

Pin | Verbindung
LV | +3V3_LOGIC
GND | GND
LV1 | GPIO 1 über R6
LV2 | GPIO 7

### HV-Seite (5V)

Pin | Verbindung
HV | +5V_SYS
HV1 | FEETECH_DATA
HV2 | FEETECH_DATA

Wichtig: HV1 und HV2 werden gemeinsam auf FEETECH_DATA verbunden.

### Widerstände

Bauteil | Wert | Anschluss
R6 | 220Ω | GPIO 1 → LV1 (Serienwiderstand)
R8 | 2.2kΩ | FEETECH_DATA → +5V_SYS (Bus Pullup)

### J3 – Feetech Bus Connector

Pin | Verbindung
1 | GND
2 | +5V_SYS
3 | FEETECH_DATA

Feetech-Bus Level Shifter Schaltplan

## 11. USB / JTAG

GPIO18 und GPIO19 nicht verbinden.

Keine Leiterbahnen. Keine Pullups. Keine Testpads.

## 12. Empfohlene Footprints

Bauteil | Footprint
0603 Widerstände | R_0603_1608Metric
100nF | C_0603_1608Metric
10µF | C_0805_2012Metric
47µF | C_1206_3216Metric
470µF Elko | CP_Radial_D10.0mm_P5.00mm
TVS | D_SMB
TMC2209 Modul | PinSocket_2x08_P2.54mm
ESP32-C3 | Custom Module Footprint

## 13. PCB Layoutregeln

### Ground Plane

- Top Layer vollständige GND-Fläche
- Bottom Layer vollständige GND-Fläche
- Viele Stitching-Vias

### TMC2209 Thermal

- Unter Exposed Pad mindestens 5 Thermal Vias
- 0.3mm Drill, 0.6mm Diameter

### Empfohlene Leiterbahnbreiten

Signal | Breite
Logic | 0.20mm
5V | 0.50mm
VMOT | 1.20mm
Motorphasen | 1.50mm

### Routing-Hinweise

- Motorleitungen: breit, kurz, symmetrisch
- I2C: kurz halten, fern von Motorleitungen, möglichst keine Vias
- PDN_UART nicht parallel zu STEP routen

## 14. ERC-Regeln

### ✓ Zulässig

- Gemeinsame UART Leitung
- Offene GPIO18 / GPIO19
- Pullup auf EN

### ✗ Nicht zulässig

- VIO an 5V
- Fehlender PDN Pullup
- Fehlender VMOT Bulk-Elko

## 15. Fertigungsregeln

Parameter | Empfehlung
Layer | 2 Layer ausreichend, 4 Layer empfohlen
Kupfer | 1oz Minimum
Substrat | 1.6mm FR4

## 16. Finale elektrische Freigabe

Design verifiziert ✓

- ESP32-C3 Bootverhalten
- TMC2209 UART (Two-Wire)
- Half Duplex Feetech Bus
- AS5600 I2C
- 3.3V / 5V Pegel
- Motorversorgung
- EMV-Grundregeln
- Entkopplung
- Thermal Management

Kann direkt als Grundlage für ein vollständiges KiCad-Projekt verwendet werden.

SmartServoStepperV2 – Verifiziert gegen Firmware (Mai 2026)

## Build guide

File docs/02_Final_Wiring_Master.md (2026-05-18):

# Hardware-Spezifikation: Smart Servo Stepper V2

**Dokument-Version:** 1.6 (Final Revision – Approved)
**Projekt-Status:** Finalisiert für PCB-Layout
**Letzte Änderung:** 13.05.2026

---

## 1. Systemarchitektur & Power Grid

Das Design ist auf maximale Stabilität bei hohen Motorlasten und Schutz der MCU ausgelegt.

### VMOT (12V–24V)

| Komponente | Funktion | Spezifikation |
| :--- | :--- | :--- |
| **SMBJ24A** | TVS-Diode, transiente Überspannungen | Kathode → VMOT, Anode → GND |
| **C_HF (100 nF)** | Keramik-Kondensator, HF-Filterung | VMOT ↔ GND, direkt am Eingang |
| **C_BULK (470 µF / 50V)** | Elko (Low-ESR), Pufferung | VMOT ↔ GND, unmittelbar am TMC2209 VM/GND |

### 5V System (SYS)

| Komponente | Funktion | Spezifikation |
| :--- | :--- | :--- |
| **MP1584EN** | Buck-Converter | Eingang: VMOT, Ausgang: 5V |
| **C_BUCK (22 µF)** | Keramik, lokaler Ausgangspuffer | Am MP1584EN Ausgang |
| **C_MCU_E (100 µF)** | Elko, MCU-Puffer | Am ESP32 5V-Pin |
| **C_MCU_K (47 µF)** | Keramik (X7R, 1206, ≥16V) | Am ESP32 5V-Pin |
| **C_MCU_HF (100 nF)** | Keramik, HF-Filterung | Direkt am ESP32 5V-Pin |

> [!IMPORTANT]
> Der 47 µF Keramik-Kondensator **muss** X7R-Dielektrikum besitzen und für mindestens 10V (besser 16V) spezifiziert sein, um den Kapazitätsverlust bei 5V Bias zu minimieren.

### 3.3V Logik (LOGIC)

| Komponente | Funktion | Spezifikation |
| :--- | :--- | :--- |
| **VIO TMC2209** | Logik-Pegel Referenz | **Zwingend 3.3V** (nicht 5V!) |
| **C_AS5600 (10 µF)** | Keramik, Sensor-Puffer | Nahe am AS5600, 3.3V ↔ GND |

> [!CAUTION]
> VIO des TMC2209 **muss** mit 3.3V verbunden werden, um Pegel-Kompatibilität zum ESP32 sicherzustellen. Eine Verbindung mit 5V kann den ESP32 beschädigen!

---

## 2. Finales Pin-Mapping (ESP32-C3 Super Mini)

Optimiert zur Vermeidung von Boot-Strap-Konflikten und Sicherstellung der USB-Funktionalität.

| ESP32-C3 Pin | Funktion | Beschreibung | Hardware-Beschaltung |
| :--- | :--- | :--- | :--- |
| **GPIO 6** | UART TMC | PDN_UART Kommunikation | 1 kΩ Schutzwiderstand in Serie |
| **GPIO 1** | Feetech TX | Bus Senden (Half-Duplex) | Via BSS138 Level Shifter (3.3V → 5V) |
| **GPIO 7** | Feetech RX | Bus Empfangen (Half-Duplex) | Via Spannungsteiler (5V → 3.3V) |
| **GPIO 2** | DIAG TMC | StallGuard / Diagnose | 4.7 kΩ Pull-UP gegen 3.3V |
| **GPIO 3** | ENABLE | TMC2209 EN (Active LOW) | 10 kΩ Pull-UP gegen 3.3V (Boot = AUS) |
| **GPIO 10** | SDA | I2C Daten (AS5600) | 4.7 kΩ Pull-UP gegen 3.3V |
| **GPIO 20** | SCL | I2C Takt (AS5600) | 4.7 kΩ Pull-UP gegen 3.3V |
| **GPIO 4** | STEP | Schritt-Impuls | Direkt |
| **GPIO 5** | DIR | Richtungs-Signal | Direkt |
| **GPIO 8** | Status-LED | On-Board LED (Blau) | Intern (Active LOW) |
| **GPIO 18/19** | USB/JTAG | D- / D+ | **Physisch unbeschaltet lassen!** |

---

## 3. Spezifische Schaltungsdetails

### 3.1 ENABLE-Logik (Kritisch)

Um unkontrollierte Motorbewegungen beim Einschalten oder Flashen zu verhindern:

| Aspekt | Detail |
| :--- | :--- |
| **Logik** | TMC2209 EN ist **Active LOW**. Der 10 kΩ Pull-Up an GPIO 3 zieht den Pin beim Booten auf **HIGH** → Motor **deaktiviert**. |
| **Firmware-Handling** | Erst nach vollständiger Initialisierung aller Sensoren wird GPIO 3 aktiv auf **LOW** gezogen (Motor aktiviert). |

> [!WARNING]
> Ohne den Pull-Up könnte GPIO 3 beim Boot floaten und den Motor unkontrolliert ansteuern. Dies ist ein **sicherheitskritisches** Detail.

### 3.2 DIAG-Schnittstelle

Der DIAG-Ausgang des TMC2209 ist **Open-Drain**.

| Aspekt | Detail |
| :--- | :--- |
| **Anbindung** | Direkt an GPIO 2 |
| **Pull-Up** | Externer 4.7 kΩ gegen 3.3V definiert das High-Level |
| **Hinweis** | Keine Anbindung an 5V oder GND-Teiler erforderlich |

### 3.3 Feetech-Bus (High-Speed 1 Mbps)

Um Signalverzögerungen durch den BSS138 im bidirektionalen Betrieb zu umgehen, nutzen wir **zwei getrennte Pfade** am ESP32, die auf der **5V-Seite zusammengeführt** werden:

```
┌─────────────┐                              ┌──────────────┐
│  ESP32-C3   │                              │  5V Feetech  │
│             │    BSS138 Level Shifter      │     Bus      │
│   GPIO 1 ──┼──── 3.3V → 5V ──────────────►├──────────────┤
│   (TX)      │                              │              │
│             │    Spannungsteiler            │              │
│   GPIO 7 ──┼◄── 4.7kΩ + 10kΩ/GND ────────┤              │
│   (RX)      │    (5V → 3.3V)              │              │
└─────────────┘                              └──────┬───────┘
                                                    │
                                              2.2kΩ Pull-Up
                                              gegen 5V
                                           (Terminierung)
```

| Pfad | Signal-Weg | Beschaltung |
| :--- | :--- | :--- |
| **TX-Pfad** | GPIO 1 → BSS138 → 5V-Bus | Level Shifter 3.3V → 5V |
| **RX-Pfad** | 5V-Bus → Spannungsteiler → GPIO 7 | 4.7 kΩ in Serie, 10 kΩ gegen GND |
| **Terminierung** | Am Bus-Ausgang | 2.2 kΩ Pull-Up gegen 5V für scharfe Signalflanken |

---

## 4. Passive Bauteile – Zusammenfassung

### 4.1 Kondensatoren

| Bezeichnung | Wert | Typ | Position |
| :--- | :--- | :--- | :--- |
| C_TVS | 100 nF | Keramik | VMOT ↔ GND, am Eingang |
| C_BULK | 470 µF / 50V | Elko (Low-ESR) | VMOT ↔ GND, am TMC2209 |
| C_BUCK | 22 µF | Keramik | MP1584EN Ausgang |
| C_MCU_E | 100 µF | Elko | ESP32 5V-Pin |
| C_MCU_K | 47 µF | Keramik (X7R, 1206, ≥16V) | ESP32 5V-Pin |
| C_MCU_HF | 100 nF | Keramik | ESP32 5V-Pin |
| C_AS5600 | 10 µF | Keramik | AS5600 3.3V ↔ GND |

### 4.2 Widerstände

| Bezeichnung | Wert | Position / Funktion |
| :--- | :--- | :--- |
| R_SDA | 4.7 kΩ | GPIO 10 (SDA) → 3.3V Pull-Up |
| R_SCL | 4.7 kΩ | GPIO 20 (SCL) → 3.3V Pull-Up |
| R_EN | 10 kΩ | GPIO 3 (ENABLE) → 3.3V Pull-Up (Boot-Safe) |
| R_DIAG | 4.7 kΩ | GPIO 2 (DIAG) → 3.3V Pull-Up |
| R_UART | 1 kΩ | GPIO 6 → TMC2209 PDN_UART (Serienwiderstand) |
| R_TERM | 2.2 kΩ | Feetech 5V-Bus → 5V Pull-Up (Terminierung) |
| R_DIV1 | 4.7 kΩ | Feetech RX Spannungsteiler (Serie) |
| R_DIV2 | 10 kΩ | Feetech RX Spannungsteiler (gegen GND) |

### 4.3 Schutzkomponenten

| Bezeichnung | Typ | Position |
| :--- | :--- | :--- |
| D_TVS | SMBJ24A | VMOT Eingang, Kathode → VMOT |
| U_LS | BSS138 Level Shifter | Feetech TX (3.3V → 5V) |

---

## 5. Layout- & Fertigungshinweise

| Thema | Vorgabe |
| :--- | :--- |
| **Thermal Management** | Großflächige Ground-Planes auf Top- und Bottom-Layer. Unter dem TMC2209 „Exposed Pad" mindestens **5 Thermal Vias** (0.3 mm Bohrung) setzen. |
| **EMI-Schutz** | I2C-Leitungen (SDA/SCL) so kurz wie möglich und **räumlich getrennt** von Motor-Leitungen (Phasen A/B). |
| **Kondensator-Platzierung** | Alle Abblock-Kondensatoren (100 nF) direkt an den zugehörigen IC-Pins. MCU-Puffer-Kondensatoren in unmittelbarer Nähe zum ESP32 5V-Pin. |
| **Mechanik** | Zentrales **6 mm Loch** für Magnet-Halterung der Motorwelle (AS5600 Encoder). |

---

## 6. Änderungshistorie

| Version | Änderungen |
| :--- | :--- |
| **V1.5 → V1.6** | ENABLE-Logik auf Pull-Up korrigiert (Boot-Sicherheit). DIAG-Schaltung auf simplen Pull-Up vereinfacht. Feetech-Bus auf dedizierte TX/RX-Pins (GPIO 1 / GPIO 7) für 1 Mbps Stabilität optimiert. GPIO 0 Boot-Konflikt aufgelöst (STEP → GPIO 4, DIR → GPIO 5). I2C auf GPIO 10/20 verlegt. Vollständiges Power-Grid mit TVS-Diode und spezifizierten Puffer-Kondensatoren dokumentiert. |
| **V1.4 → V1.5** | Initiale Konsolidierung des Verdrahtungsplans für V2-Architektur. |

---

*Erstellt am 12.05.2026, aktualisiert am 13.05.2026 durch Antigravity AI für Smart Servo Stepper V2 Projekt.*
*Dokument-Status: **FREIGEGEBEN** für PCB-Layout.*

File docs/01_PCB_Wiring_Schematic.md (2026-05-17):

# SmartServoStepperV2 – PCB Wiring & Schaltplan (v2.0 Verified)

Dieses Dokument ist der **Master-Bauplan** für das PCB-Layout, abgeglichen mit der Hardware-Spezifikation v2.0 (Stabilisiert & Getestet).

---

## 1. Systemarchitektur & Power Grid

### VMOT (12V–24V)
- **Schutz:** SMBJ24A TVS-Diode (transiente Überspannungen) + 100nF Keramik (HF)
- **Puffer:** 470 µF / 50V Elko (Low-ESR) unmittelbar am TMC2209 VM/GND

### 5V System (SYS)
- **Quelle:** MP1584EN Buck-Converter (Ausgang lokal gepuffert mit 22µF Keramik)
- **MCU-Puffer:** 100 µF Elko + 47 µF Keramik (X7R, 1206) + 100 nF direkt am ESP32 5V-Pin

### 3.3V Logik (LOGIC)
- **VIO TMC2209:** Zwingend mit 3.3V verbinden (nicht 5V!)
- **AS5600 Puffer:** 10 µF Keramik nahe am Sensor

---

## 2. Finales Pin-Mapping (ESP32-C3 Super Mini)

| ESP32-C3 Pin | Funktion | Beschreibung | Hardware-Beschaltung |
| :--- | :--- | :--- | :--- |
| **GPIO 0** | SDA | I2C Daten (AS5600) | 4.7kΩ Pull-UP gegen 3.3V |
| **GPIO 1** | Feetech TX | Bus Senden (Half-Duplex) | Via 220Ω Serienwiderstand → BSS138 Level Shifter |
| **GPIO 2** | DIR | Richtungs-Signal | Direkt |
| **GPIO 3** | ENABLE | TMC2209 EN (Active LOW) | 10kΩ Pull-UP gegen 3.3V (Boot = AUS) |
| **GPIO 4** | STEP | Schritt-Impuls | Direkt |
| **GPIO 5** | UART RX | TMC2209 Kommunikation | Direkt an PDN_UART (TMC) |
| **GPIO 6** | UART TX | TMC2209 Kommunikation | **1kΩ Schutzwiderstand** in Serie zu PDN_UART |
| **GPIO 7** | Feetech RX | Bus Empfangen (Half-Duplex) | Direkt → BSS138 Level Shifter |
| **GPIO 8** | Status-LED | On-Board LED (Blau) | Intern (Active LOW) |
| **GPIO 10** | SCL | I2C Takt (AS5600) | 4.7kΩ Pull-UP gegen 3.3V |
| **GPIO 18/19** | USB/JTAG | D- / D+ | **Physisch unbeschaltet lassen!** (Intern für USB reserviert) |

---

## 3. Spezifische Schaltungsdetails

### 3.1 ENABLE-Logik (Kritisch)
- **Logik:** TMC2209 aktiv bei LOW. 10kΩ Pull-Up zieht GPIO 3 beim Booten auf HIGH (Disabled).
- **Firmware:** Erst nach Initialisierung aller Sensoren (AS5600, TMC2209) wird GPIO 3 aktiv auf LOW gezogen.

### 3.2 Schritt- & Richtungssteuerung (STEP/DIR)
- **DIR (Richtung):** GPIO 2.
- **STEP (Schritt):** GPIO 4.
- **Firmware:** Werden über die `FastAccelStepper`-Library direkt angesteuert.

### 3.3 Feetech-Bus (High-Speed 1 Mbps)

TX- und RX-Pfade gehen beide auf den Level Shifter und werden auf der HV-Seite (5V) zusammengeführt:

```text
ESP32-C3                                             Feetech Bus (5V)
─────────                                            ────────────────
GPIO 1 (TX) ──→ 220Ω ──→ BSS138 (LV1) ──→ (HV1) ──┐
                                                  ├── DATA (1-Wire)
GPIO 7 (RX) ───────────→ BSS138 (LV2) ←── (HV2) ──┘
                                                  │
                                            2.2kΩ Pull-Up → 5V
                                         (Terminierung / scharfe Flanken)
```

- **TX-Pfad:** GPIO 1 → 220Ω Serienwiderstand → Level Shifter (LV1) → 5V Bus (HV1)
- **RX-Pfad:** GPIO 7 → Level Shifter (LV2) ← 5V Bus (HV2)
- **Terminierung:** 2.2kΩ Pull-Up gegen 5V am Bus-Ausgang

### 3.4 TMC2209 UART (Two-Wire Control)
- **GPIO 5 (RX)** → Direkt an TMC2209 PDN_UART.
- **GPIO 6 (TX)** → 1kΩ Serienwiderstand (R5) → TMC2209 PDN_UART.
- **Pull-Up:** Ein **4.7kΩ Widerstand (R9)** von PDN_UART nach 3.3V ist zwingend erforderlich für Signalintegrität.
- **Firmware:** SoftwareSerial bei **19200 baud**.

---

## 4. Stückliste (BOM)

### Aktive Bauteile
| Typ | Bauteil / Modul | Menge | Funktion |
| :--- | :--- | :--- | :--- |
| **MCU** | ESP32-C3 Super Mini | 1x | Hauptprozessor (Single-Core, 160MHz, WLAN) |
| **Driver** | TMC2209 Stepper Driver | 1x | Ultra-leiser Treiber (UART, StealthChop, CoolStep, StallGuard) |
| **Sensor** | AS5600 Magnetic Encoder | 1x | 12-Bit Absolut-Encoder (I²C) |
| **Comms** | BSS138 Level Shifter | 1x | 3.3V→5V für Feetech TX-Pfad |
| **Power** | MP1584EN Buck Converter | 1x | 12V→5V Step-Down |
| **Schutz** | SMBJ24A TVS-Diode | 1x | Transientenschutz VMOT |

### Passivbauteile
| ID | Bauteil | Wert | Position |
| :--- | :--- | :--- | :--- |
| C1 | Elko (Low-ESR, 50V) | 470 µF | VMOT / GND (am TMC2209) |
| C2 | Keramik | 100 nF | VMOT / GND (HF-Filter) |
| C3 | Keramik (X7R, 1206) | 47 µF | ESP32 5V / GND |
| C4 | Keramik | 100 nF | ESP32 5V / GND (Entkopplung) |
| C5 | Elko | 100 µF | ESP32 5V / GND (Bulk) |
| C6 | Keramik | 22 µF | Buck-Converter Ausgang |
| C7 | Keramik | 10 µF | AS5600 3.3V / GND |
| R1 | Widerstand | 4.7 kΩ | SDA (GPIO 0) → 3.3V (I2C Pull-Up) |
| R2 | Widerstand | 4.7 kΩ | SCL (GPIO 10) → 3.3V (I2C Pull-Up) |
| R3 | Widerstand | 10 kΩ | EN (GPIO 3) → 3.3V (Boot-Safe) |
| R5 | Widerstand | 1 kΩ | GPIO 6 (TX) → TMC PDN_UART (Schutz) |
| R6 | Widerstand | 220 Ω | GPIO 1 (TX) → Level Shifter (Serie) |
| R8 | Widerstand | 2.2 kΩ | Feetech Bus Terminierung (→5V) |
| R9 | Widerstand | 4.7 kΩ | PDN_UART → 3.3V (Kommunikations-Pull-Up) |

---

## 5. Layout- & Fertigungshinweise

- **Thermal Management:** Großflächige Ground-Planes auf Top- und Bottom-Layer. Unter TMC2209 "Exposed Pad" mindestens **5 Thermal Vias** (0.3mm Bohrung).
- **EMI-Schutz:** I2C-Leitungen (SDA/SCL) so kurz wie möglich. Räumlich von Motor-Phasen (A/B) trennen.
- **Kondensatoren:** 47µF Keramik muss **X7R-Dielektrikum** besitzen, min. 10V (besser 16V).
- **Mechanik:** Zentrales **6mm Loch** für Magnet-Halterung der Motorwelle.
- **USB/JTAG:** GPIO 18/19 physisch **unbeschaltet** lassen.

---

## 6. Architektur-Diagramm

```mermaid
graph TD
    %% Power
    PSU((12V-24V)) -->|VMOT| TVS[SMBJ24A TVS]
    TVS --> C_VMOT[470µF + 100nF]
    C_VMOT --> TMC_VM[TMC2209 VMOT]
    PSU --> BUCK[MP1584EN Buck]
    BUCK -->|5V| C_5V[22µF + 100µF + 47µF + 100nF]
    C_5V --> ESP[ESP32-C3 5V]
    C_5V --> SHIFT[BSS138 HV]

    %% 3.3V
    ESP -->|3.3V| TMC_VIO[TMC2209 VIO]
    ESP -->|3.3V| C_AS[10µF → AS5600]

    %% I2C
    ESP_I2C["GPIO 0 (SDA) + GPIO 10 (SCL)"] -->|I2C 400kHz| AS5600
    3V3[3.3V] -.->|R1/R2 4.7kΩ| ESP_I2C

    %% TMC Control
    ESP4["GPIO 4"] -->|STEP| TMC_STEP[TMC2209]
    ESP2["GPIO 2"] -->|DIR| TMC_DIR[TMC2209]
    ESP3["GPIO 3"] -->|EN| TMC_EN[TMC2209]
    3V3 -.->|R3 10kΩ| ESP3

    %% TMC UART (Two-Wire Strategy)
    ESP5["GPIO 5 (RX)"] --> TMC_UART["TMC2209 PDN_UART"]
    ESP6["GPIO 6 (TX)"] -->|R5 1kΩ| TMC_UART
    3V3 -.->|R9 4.7kΩ| TMC_UART

    %% Feetech Bus
    ESP1["GPIO 1 (TX)"] -->|R6 220Ω| SHIFT_LV1["BSS138 LV1"]
    ESP7["GPIO 7 (RX)"] --> SHIFT_LV2["BSS138 LV2"]
    SHIFT_LV1 --> SHIFT_HV1["BSS138 HV1"]
    SHIFT_LV2 --> SHIFT_HV2["BSS138 HV2"]
    SHIFT_HV1 --> BUS_5V["5V Bus"]
    SHIFT_HV2 --> BUS_5V
    BUS_5V --> R8["R8 2.2kΩ→5V"]
    BUS_5V --> FEETECH((FEETECH DATA))
```

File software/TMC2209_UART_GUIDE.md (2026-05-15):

# TMC2209 UART Troubleshooting & Solution Guide (ESP32-C3)

This document describes the successful resolution of UART communication issues between an ESP32-C3 and a TMC2209 motor driver.

## 1. The Core Problem
The initial setup failed with `0x00` (no communication) or caused system brownouts (ESP32 disconnecting from USB).
- **USB-Serial Conflict:** GPIO 20 and 21 on the ESP32-C3 are natively tied to the internal USB-Serial/JTAG unit. Using them for secondary UART communication caused stability issues and crashes.
- **Signal Integrity:** The TMC2209 requires a specific single-wire UART configuration with a pull-up and a series resistor to separate the RX and TX paths of the MCU.

## 2. The Proven Solution (The "Safe Mode")
To achieve stable 0x21 version handshakes and prevent hardware damage, the following configuration was implemented:

### Hardware Wiring
| ESP32-C3 Pin | TMC2209 Pin | Component |
| :--- | :--- | :--- |
| **GPIO 5 (RX)** | PDN_UART | Direct connection |
| **GPIO 6 (TX)** | PDN_UART | **1kΩ Resistor in series** |
| **3.3V (VCC)** | PDN_UART | **4.7kΩ Pull-up Resistor** |
| **GPIO 3 (EN)** | EN | Grounded or controlled by MCU |
| **GND** | GND | Common ground is essential |

### Software Configuration
- **Library:** `TMCStepper`
- **Driver:** `SoftwareSerial` (highly recommended for C3 to avoid hardware remapping issues)
- **Baudrate:** 19200 Baud (proven stability)
- **Critical Register Flags:**
  - `pdn_disable(true)`
  - `mstep_reg_select(true)`

## 3. Implementation Steps
1. **Reset State:** Flash a blank sketch first to ensure the board is electrically stable.
2. **Sequential Power-up:** Connect Logic Power (3.3V/GND) first, verify USB stability, then connect Motor Power (12V).
3. **UART Handshake:** Use the diagnostic script to poll the version register. `0x21` confirms success.

## 4. Final Pin Mapping
```cpp
#define UART_RX_PIN 5
#define UART_TX_PIN 6
#define EN_PIN      3
#define STEP_PIN    18
#define DIR_PIN     19
```

---
*Status: Verified and Operational (2026-05-15)*

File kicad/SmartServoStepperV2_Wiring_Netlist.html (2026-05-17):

# SmartServoStepperV2

Modul-Pinouts · Stromlaufplan · Point-to-Point Netlist

ESP32-C3 Super Mini Tenstar TMC2209 V2 AS5600 Encoder BSS138 Level Shifter MP1584EN Buck

## 1. Modul-Pinouts & interne Besonderheiten

### ESP32-C3 Super Mini

Das Modul speist sich über den 5V Pin (der interne Regler erzeugt daraus die 3.3V, die am 3V3 Pin für externe Sensorik abgegriffen werden können).

### Tenstar TMC2209 V2 Module (SilentStepStick-Format)

Wichtig bei Tenstar V2: Der Pin PDN_UART liegt standardmäßig auf dem Pin, der bei klassischen Treibern (wie A4988) als INDEX oder PDN beschriftet ist (meistens der 4. Pin von oben auf der linken Seite, direkt unter SP oder EN).

- VIO / VM: VIO ist die Logikspannung (3.3V) und VM die Motorspannung (12V–24V).
- DIAG: Kann unbeschaltet bleiben (wird für StallGuard/sensorloses Homing genutzt).

## 2. Modul-zu-Modul Stromlaufplan

### Block A: Power Grid (Stromversorgung)

#### VMOT Eingang (12–24V)

[ NETZTEIL 12V-24V ] │ ├──( + )───┬─── [ SMBJ24A TVS-Diode ] ───( GND ) │ ├─── [ C2: 100nF Keramik ] ───( GND ) │ ├───► [ MP1584EN INPUT (IN+) ] │ │ │ └───► [ Tenstar TMC2209 - Pin: VM ] │ │ │ └─── [ C1: 470µF Elko ] ───( GND ) *Direkt am Modul-Pin! │ └──( - )───► Zentraler GND-Knoten

#### 5V Systemversorgung

[ MP1584EN OUTPUT (OUT+) ] (5V_SYS) │ ├───┬─── [ C6: 22µF Keramik ] ───( GND ) │ │ │ ├───► [ ESP32-C3 Super Mini - Pin: 5V ] │ │ │ │ │ ├─── [ C5: 100µF Elko ] ───( GND ) │ │ ├─── [ C3: 47µF Keramik ] ───( GND ) │ │ └─── [ C4: 100nF Keramik ] ───( GND ) │ │ │ └───► Feetech-Bus (VCC) & [ R8: 2.2kΩ Pull-Up ]

#### 3.3V Logic Rail

[ ESP32-C3 Super Mini - Pin: 3V3 ] (3V3_LOGIC) │ ├───► [ Tenstar TMC2209 - Pin: VIO ] ├───► [ AS5600 - Pin: VDD ] ───┬─── [ C7: 10µF Keramik ] ───( GND ) ├───► BSS138 Level Shifter (Gate 1 & Gate 2) └───► Pull-Up-Widerstände (R1, R2, R3, R9)

### Block B: Spezifische Modul-Verbindungen

#### 1. TMC2209 UART Eindraht-Bus (TMC_UART_NODE)

Info: Da du das Tenstar-Modul nutzt, verbinden wir die Pins über die Schutzwiderstände direkt mit dem UART-Pin des Moduls.

ESP32-C3 Pin: GPIO 5 (RX) ──────────────────────────┬───► [ Tenstar TMC2209 - Pin: PDN_UART ] │ ESP32-C3 Pin: GPIO 6 (TX) ─── [ R5: 1 kΩ Serie ] ───┤ │ 3V3_LOGIC ────────────────── [ R9: 4.7 kΩ Pull-Up ] ┘

#### 2. Feetech Bus (Level Shifter mit BSS138)

[ 3V3_LOGIC ] ───┬──────────────────────────────┐ │ │ Gate 1 Gate 2 │ │ GPIO 1 ── [ R6: 220Ω ] ── Source 1 Source 2 ─── ESP32-C3 Pin: GPIO 7 │ Drain 1 ─────────────────────── Drain 2 │ ├─── [ R8: 2.2 kΩ Pull-Up ] ─── [ 5V_SYS ] │ └───► [ FEETECH BUS - PIN: DATA ]

#### 3. Motor-Treiber Signale (Steuerung)

ESP32-C3 Pin: GPIO 2 ───────────────────────────────► [ Tenstar TMC2209 - Pin: DIR ] ESP32-C3 Pin: GPIO 4 ───────────────────────────────► [ Tenstar TMC2209 - Pin: STEP ] ESP32-C3 Pin: GPIO 3 ───┬───────────────────────────► [ Tenstar TMC2209 - Pin: EN ] │ [ R3: 10 kΩ Pull-Up ] ───► [ 3V3_LOGIC ]

## 3. Vollständige Point-to-Point Netzliste

Diese Netlist zeigt exakt, welche Pins der Module auf der Platine miteinander verbunden werden müssen.

#### 5V_SYS

- MP1584EN (OUT+)
- C6 (Pluspol)
- ESP32-C3 Modul (Pin: 5V)
- C5 (Elko Pluspol)
- C3 (Pin 1)
- C4 (Pin 1)
- Widerstand R8 (Pin 1)
- Feetech Bus-Stecker (Pin: VCC)

#### 3V3_LOGIC

- ESP32-C3 Modul (Pin: 3V3)
- Tenstar TMC2209 Modul (Pin: VIO)
- AS5600 Sensor (Pin: VDD)
- C7 (Pin 1)
- Widerstand R1 (Pin 1)
- Widerstand R2 (Pin 1)
- Widerstand R3 (Pin 1)
- Widerstand R9 (Pin 1)
- BSS138 MOSFET (Gate 1 und Gate 2)

#### GND

Masseverbindung für absolut alles: Netzteil (−), TVS-Diode (Anode), C1(−), C2(−), C3(−), C4(−), C5(−), C6(−), C7(−), MP1584EN (GND), ESP32-C3 Modul (GND), Tenstar TMC2209 Modul (GND), AS5600 (GND), Feetech-Stecker (GND).

#### TMC_UART_NODE

- ESP32-C3 Modul (Pin: GPIO 5)
- Widerstand R5 (Pin 2)
- Widerstand R9 (Pin 2)
- Tenstar TMC2209 Modul (Pin: PDN_UART)

#### FT_5V_BUS

- BSS138 (Drain 1)
- BSS138 (Drain 2)
- Widerstand R8 (Pin 2)
- Feetech Bus-Stecker (Pin: DATA)

## 4. Wichtige Vereinfachung für dein PCB-Layout

Da du fertige Module nutzt, reduziert sich dein Layout-Aufwand drastisch:

Thermal Management

Da du das Tenstar-Modul fertig zukaufst, musst du dich nicht um die Thermal Vias unter dem IC kümmern – das hat Tenstar bereits erledigt. Du musst nur sicherstellen, dass Luft an das Modul kommt (ggf. kleiner Kühlkörper aufkleben).

Kondensatoren-Vorteil

Die Kondensatoren C3, C4, C5 für den ESP32 sowie C1 und C2 für den TMC2209 musst du trotzdem auf deiner Hauptplatine einplanen, und zwar so nah wie möglich an den Stiftleisten, wo die Module eingesteckt werden.

SmartServoStepperV2 – Modul-Wiring & Netlist · Verifiziert gegen Firmware (Mai 2026)

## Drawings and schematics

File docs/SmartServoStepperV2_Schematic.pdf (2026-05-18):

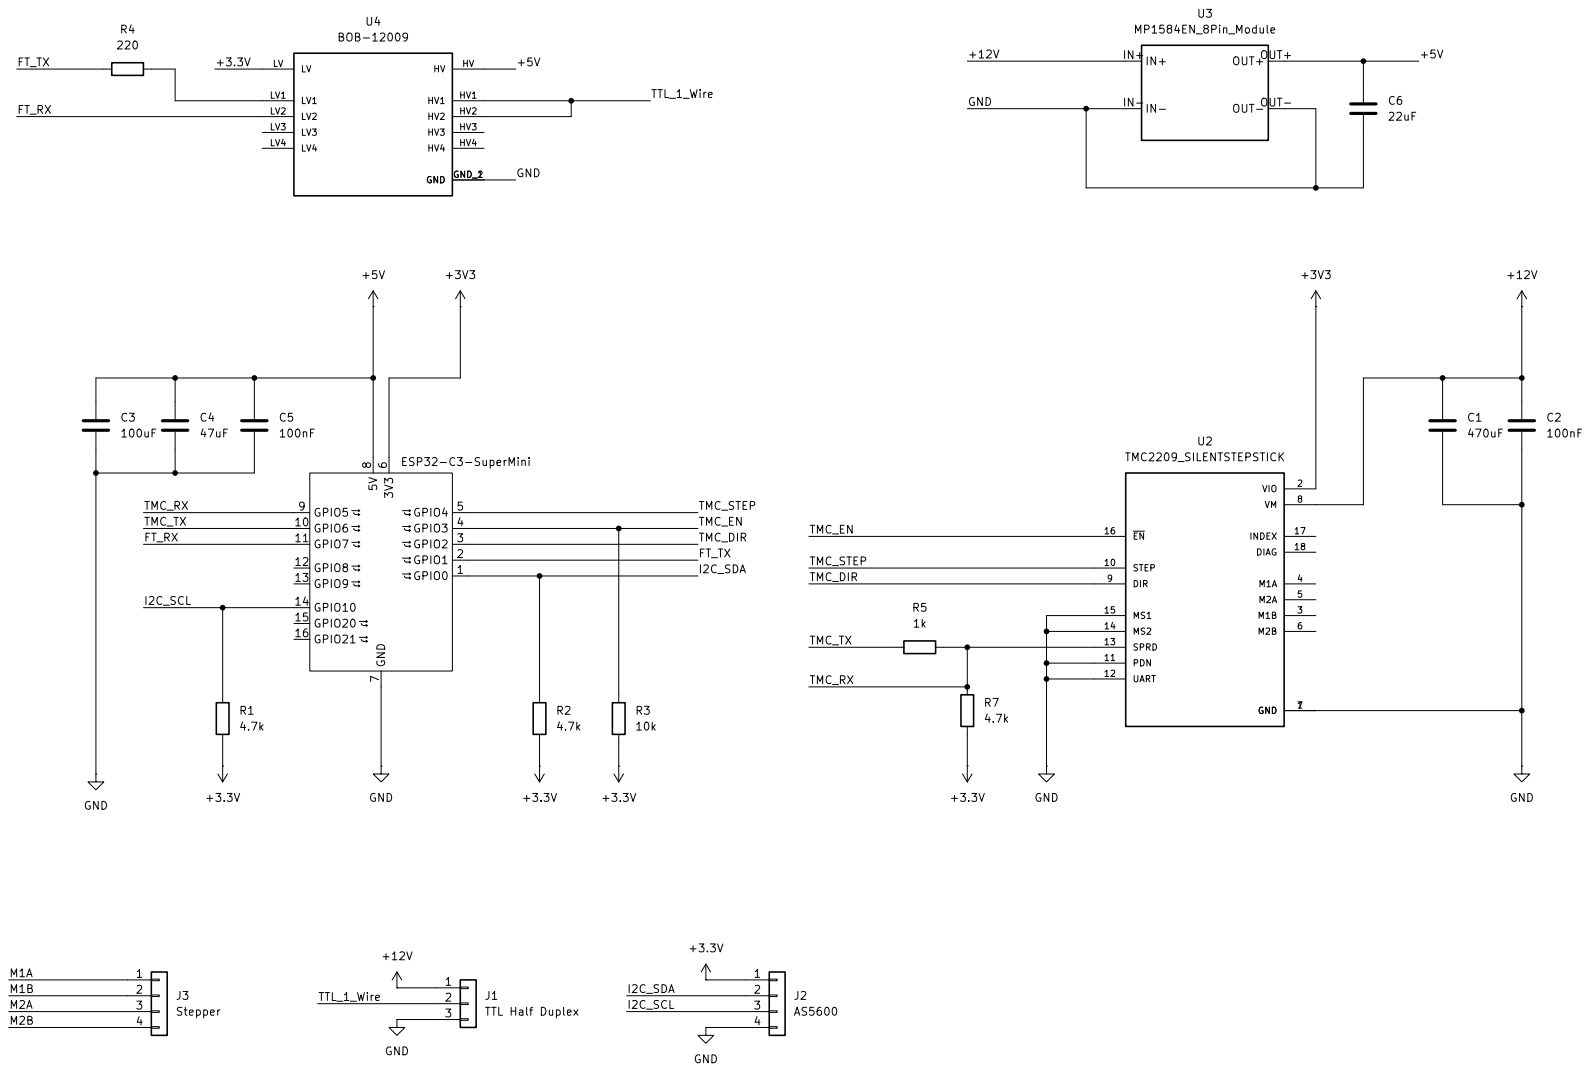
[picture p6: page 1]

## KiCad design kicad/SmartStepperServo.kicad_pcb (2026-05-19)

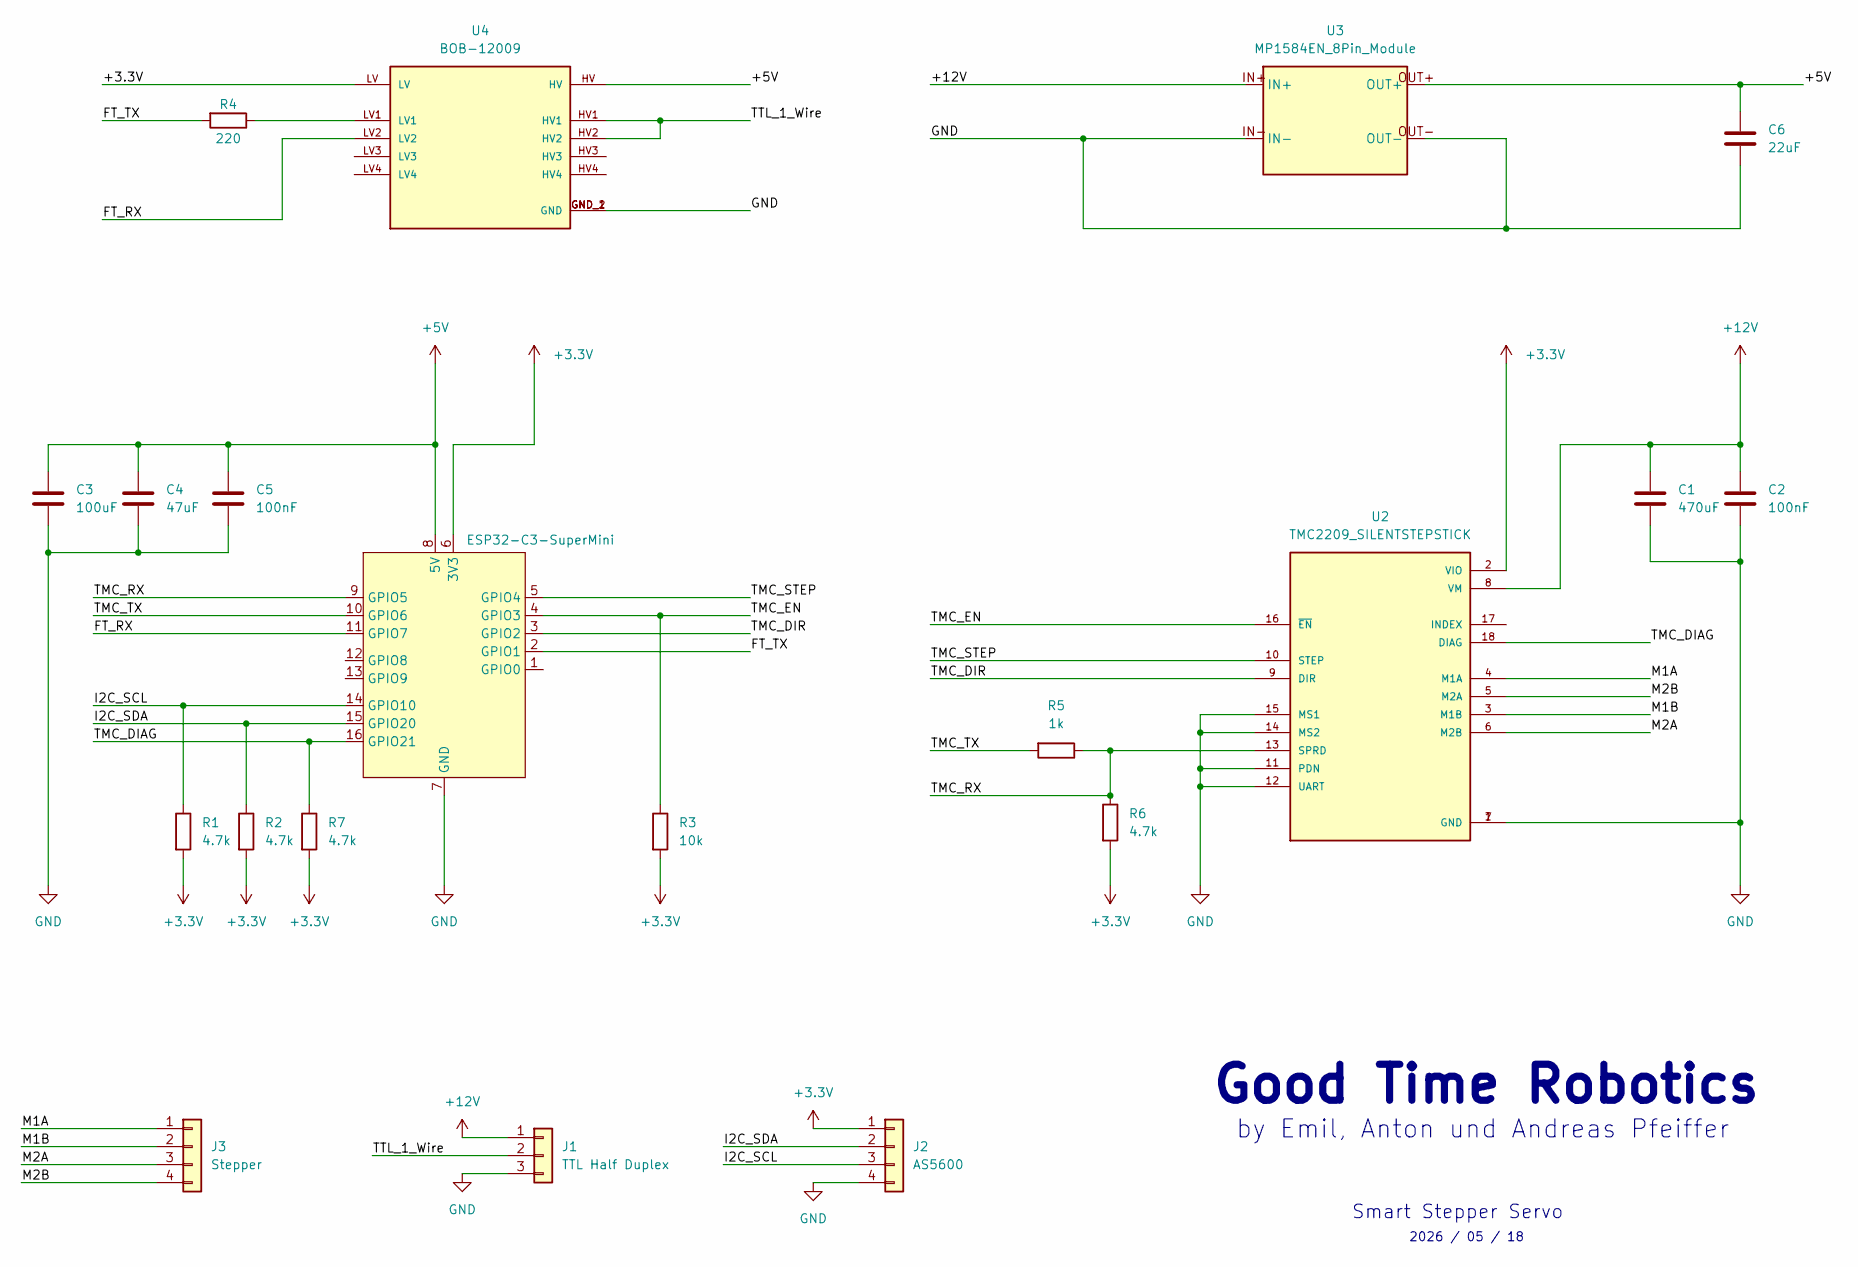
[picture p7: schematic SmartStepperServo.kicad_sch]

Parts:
C1: 470uF; CP_Radial_D6.3mm_P2.50mm
C2, C5: 100nF; C_Disc_D3.8mm_W2.6mm_P2.50mm
C3: 100uF; CP_Radial_D6.3mm_P2.50mm
C4: 47uF; CP_Radial_D6.3mm_P2.50mm
C6: 22uF; C_Disc_D3.8mm_W2.6mm_P2.50mm
J1: TTL Half Duplex; JST_XH_B3B-XH-A_1x03_P2.50mm_Vertical
J2: AS5600; JST_XH_B4B-XH-A_1x04_P2.50mm_Vertical
J3: Stepper; JST_XH_B4B-XH-A_1x04_P2.50mm_Vertical
R1, R2, R6, R7: 4.7k; R_Axial_DIN0207_L6.3mm_D2.5mm_P7.62mm_Horizontal
R3: 10k; R_Axial_DIN0207_L6.3mm_D2.5mm_P7.62mm_Horizontal
R4: 220; R_Axial_DIN0207_L6.3mm_D2.5mm_P7.62mm_Horizontal
R5: 1k; R_Axial_DIN0207_L6.3mm_D2.5mm_P7.62mm_Horizontal
U1: ESP32-C3-SuperMini
U2: TMC2209_SILENTSTEPSTICK; MODULE_TMC2209_SILENTSTEPSTICK; PARTREV 1.20
U3: MP1584EN_8Pin_Module
U4: BOB-12009; CONV_BOB-12009; PARTREV 01

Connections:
+3.3V: J2.1, R1.2, R2.2, R3.2, R6.2, R7.2, U1.6 (3V3), U2.2 (VIO), U4.LV
+5V: C3.2, C4.2, C5.2, C6.1, U1.8 (5V), U3.OUT+, U4.HV
+12V: C1.1, C2.1, J1.1, U2.8 (VM), U3.IN+
/FT_RX: U1.11 (GPIO7), U4.LV2
/FT_TX: R4.2, U1.2 (GPIO1)
/I2C_SCL: J2.3, R1.1, U1.14 (GPIO10)
/I2C_SDA: J2.2, R2.1, U1.15 (GPIO20)
/M1A: J3.1, U2.4 (M1A)
/M1B: J3.2, U2.3 (M1B)
/M2A: J3.3, U2.6 (M2B)
/M2B: J3.4, U2.5 (M2A)
/TMC_DIAG: R7.1, U1.16 (GPIO21), U2.18 (DIAG)
/TMC_DIR: U1.3 (GPIO2), U2.9 (DIR)
/TMC_EN: R3.1, U1.4 (GPIO3), U2.16 (~EN)
/TMC_RX: R5.1, R6.1, U1.9 (GPIO5), U2.13 (SPRD)
/TMC_STEP: U1.5 (GPIO4), U2.10 (STEP)
/TMC_TX: R5.2, U1.10 (GPIO6)
/TTL_1_Wire: J1.2, U4.HV1, U4.HV2
GND: C1.2, C2.2, C3.1, C4.1, C5.1, C6.2, J1.3, J2.4, U1.7 (GND), U2.1 (GND), U2.7 (GND), U2.11 (PDN), U2.12 (UART), U2.14 (MS2), U2.15 (MS1), U3.IN-, U3.OUT-, U4.GND_1 (GND), U4.GND_2 (GND)
unnamed: R4.1, U4.LV1

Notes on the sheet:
Good Time Robotics
2026 / 05 / 18
Smart Stepper Servo
by Emil, Anton und Andreas Pfeiffer

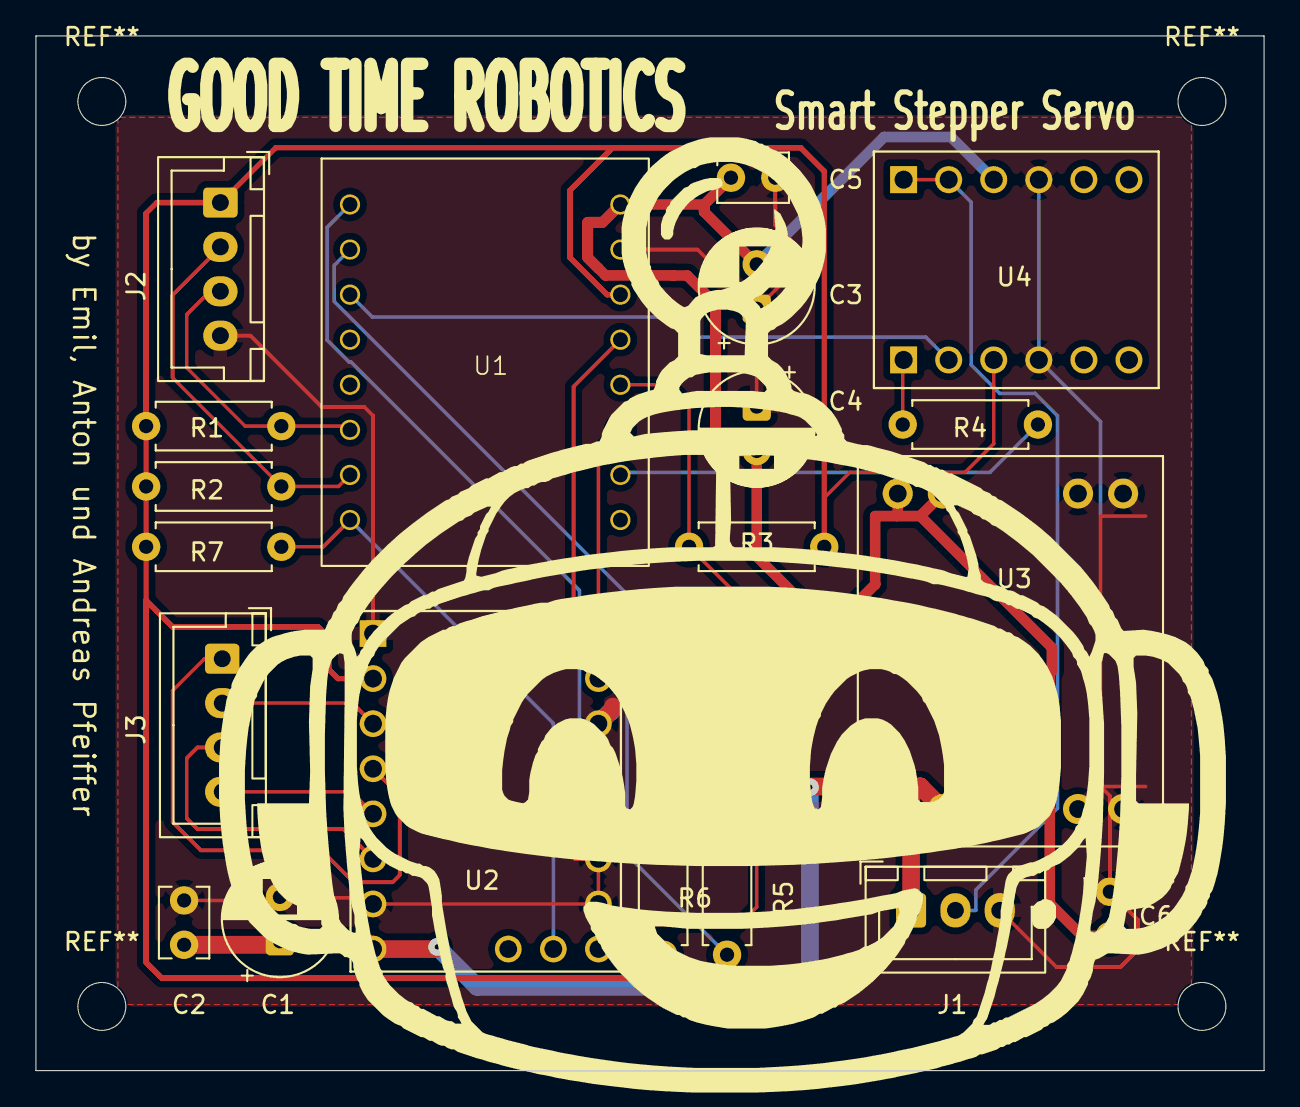
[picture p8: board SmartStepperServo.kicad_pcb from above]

Board: 2 copper layers, 69.2 x 58.3 mm, 20 parts (0 on the bottom side), 20 nets.

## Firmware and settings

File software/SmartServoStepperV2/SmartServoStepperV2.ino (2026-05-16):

// ═══════════════════════════════════════════════════════════
// SmartServoStepperV2 - OPTIMAL STEPPER DRIVER (DIRECT FREQUENCY / CNC)
// ═══════════════════════════════════════════════════════════
#include <Arduino.h>
#include <WiFi.h>
#include <WebSocketsServer.h>
#include <ArduinoJson.h>
#include <TMCStepper.h>
#include <Wire.h>
#include <AS5600.h>
#include "FastAccelStepper.h"

// --- PINS ---
#define PIN_TMC_RX      5   
#define PIN_TMC_TX      6   
#define PIN_EN          3   
#define PIN_STEP        4   
#define PIN_DIR         2   
#define PIN_SDA         0   
#define PIN_SCL         10  
#define PIN_LED         8   

const char* st_ssid = "FRITZ!Box 6660 Cable UE";
const char* st_pass = "28370714691864306613";
IPAddress local_ip(192, 168, 178, 78);
IPAddress gateway(192, 168, 178, 1);
IPAddress subnet(255, 255, 255, 0);

WebSocketsServer webSocket = WebSocketsServer(81);
HardwareSerial tmcSerial(1);
TMC2209Stepper driver(&tmcSerial, 0.11f, 0);
AS5600 as5600;

FastAccelStepperEngine engine = FastAccelStepperEngine();
FastAccelStepper *stepper = NULL;

long targetPos = 2048;
long currentSpeed = 0;
String controlMode = "pos"; 
bool isKilled = true;
float currentRPS = 0;
float lastAngle = 0;
unsigned long lastTime = 0;

// Konstanten zur Umrechnung (AS5600 -> Motor-Schritte)
const float STEPS_PER_REV = 3200.0; // 200 Vollschritte * 16 Microsteps
const float AS5600_PER_REV = 4096.0;
const float RATIO = STEPS_PER_REV / AS5600_PER_REV;

void handleWebSocket(uint8_t num, WStype_t type, uint8_t * payload, size_t length) {
    if (type == WStype_TEXT) {
        JsonDocument doc; 
        deserializeJson(doc, payload);
        
        if (doc["mode"].is<const char*>()) {
            controlMode = doc["mode"].as<String>();
        }
        
        if (doc["val"].is<long>()) {
            long val = doc["val"];
            if (controlMode == "pos") {
                targetPos = val;
                
                // Berechne den kürzesten Weg zum neuen Ziel
                float currentPos = as5600.readAngle();
                float diff = targetPos - currentPos;
                if (diff > 2048) diff -= 4096;
                if (diff < -2048) diff += 4096;
                
                // Rechne in Schritte um und adde zum aktuellen STEPPER-Ziel
                long stepsToMove = diff * RATIO;
                if (stepper && !isKilled) {
                    stepper->move(stepsToMove); 
                }
            }
            else {
                currentSpeed = val;
                if (stepper && !isKilled) {
                    if (currentSpeed == 0) {
                        stepper->stopMove();
                    } else {
                        stepper->setSpeedInHz(abs(currentSpeed * 20));
                        if (currentSpeed > 0) stepper->runForward();
                        else stepper->runBackward();
                    }
                }
            }
        }
        
        if (doc["cmd"].is<const char*>()) {
            String cmd = doc["cmd"].as<String>();
            if (cmd == "kill") { 
                isKilled = true; 
                if (stepper) stepper->stopMove(); 
                digitalWrite(PIN_EN, HIGH); 
            }
            else if (cmd == "enable") { 
                isKilled = false; 
                digitalWrite(PIN_EN, LOW); 
                if(stepper) stepper->setCurrentPosition(0); 
            }
            else if (cmd == "set_microstep") { driver.microsteps(1 << doc["value"].as<int>()); }
            else if (cmd == "tare") { targetPos = as5600.readAngle(); }
        }
    }
}

void setup() {
    delay(2000);
    Serial.begin(115200);
    WiFi.mode(WIFI_STA);
    WiFi.config(local_ip, gateway, subnet);
    WiFi.begin(st_ssid, st_pass);
    
    // Hardware Serial auf Pins 5 und 6
    tmcSerial.begin(115200, SERIAL_8N1, PIN_TMC_RX, PIN_TMC_TX);
    
    Wire.begin(PIN_SDA, PIN_SCL);
    Wire.setClock(400000); 
    
    pinMode(PIN_EN, OUTPUT);
    pinMode(PIN_LED, OUTPUT);
    digitalWrite(PIN_EN, HIGH);
    
    // TMC2209 Optimal Setup
    driver.begin();
    driver.pdn_disable(true);
    driver.I_scale_analog(false);
    driver.mstep_reg_select(true);
    driver.rms_current(1000); 
    driver.en_spreadCycle(true);
    driver.microsteps(16);
    driver.blank_time(24);
    driver.toff(4);
    
    // Hardware Timer initialisieren für Stepper
    engine.init();
    stepper = engine.stepperConnectToPin(PIN_STEP);
    if (stepper) {
        stepper->setDirectionPin(PIN_DIR);
        stepper->setAutoEnable(false); 
        
        // Direkte Frequenz-Methode Parameter:
        stepper->setSpeedInHz(40000); // Maximale Reisegeschwindigkeit
        stepper->setAcceleration(25000); // Saubere Beschleunigungsrampe (Anti-Stall)
    }
    
    webSocket.begin();
    webSocket.onEvent(handleWebSocket);
    lastAngle = as5600.readAngle();
    lastTime = micros();
}

void loop() {
    webSocket.loop();
    unsigned long now = micros();
    float dt = (now - lastTime) / 1000000.0;
    
    // Sensor nur noch für Telemetrie auslesen
    if (dt >= 0.02) { 
        float currentPos = as5600.readAngle();
        float diff = currentPos - lastAngle;
        if (diff > 2048) diff -= 4096;
        if (diff < -2048) diff += 4096;
        currentRPS = (diff / 4096.0) / dt;
        lastAngle = currentPos;
        lastTime = now;
    }
    
    static uint32_t lastTele = 0;
    if (millis() - lastTele > 50) { 
        lastTele = millis();
        JsonDocument out; 
        out["pos"] = as5600.readAngle();
        out["rps"] = abs(currentRPS); 
        out["tmc"] = (driver.version() == 0x21) ? "OK" : "ERR";
        out["k"] = isKilled ? 1 : 0;
        out["sp"] = targetPos;
        out["err"] = 0; // Fehler gibts nicht mehr, da offener Kreis
        out["pid"] = 0;
        
        String json;
        serializeJson(out, json);
        webSocket.broadcastTXT(json);
        digitalWrite(PIN_LED, !digitalRead(PIN_LED));
    }
}

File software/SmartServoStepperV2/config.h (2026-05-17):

// ═══════════════════════════════════════════════════════════
// SmartServoStepperV2 - PIN CONFIGURATION v2.5 STABLE
// ═══════════════════════════════════════════════════════════
#ifndef CONFIG_H
#define CONFIG_H

// --- TMC2209 PINOUT ---
#define PIN_TMC_RX      5   // UART RX (Direct to PDN_UART)
#define PIN_TMC_TX      6   // UART TX (via 1k Resistor to PDN_UART)
#define PIN_EN          3   // ENABLE (Active LOW)
#define PIN_STEP        4   // STEP (Optional, using UART VACTUAL for primary move)
#define PIN_DIR         2   // DIR (Optional)

// --- AS5600 I2C PINOUT ---
#define PIN_SDA         0   // I2C Data
#define PIN_SCL         10  // I2C Clock

// --- STATUS ---
#define PIN_LED         8   // Onboard Blue LED

// --- PARAMETERS ---
#define TMC_RMS_CURRENT 1000 // 1A
#define TMC_DRIVER_ADDR 0b00
#define TMC_SENSE_RES   0.11f

#endif

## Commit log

2026-05-12 Initial commit: V2 Hardware Documentation with ESP32-C3 and TMC2209
2026-05-12 Added ESP32-C3 Firmware and KiCad project structure
2026-05-12 Added premium HTML version of the PCB wiring schematic
2026-05-15 FIX: Established stable TMC2209 UART communication on GPIO 5/6
    [FeetechProtocol.cpp, SmartServoStepperV2.ino, TMC_UART_Test.ino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]
2026-05-15 DOCS: Updated master schematic to v2.0 Verified with final protection circuit details
2026-05-16 Final stable release v2.9.2 - Complete hardware fix, PID position control, and dashboard integration
    [SmartServoStepperV2.ino, config.h]
2026-05-16 Refactor: Switch to pure Direct Frequency (CNC) control via FastAccelStepper. Removed PID loops to eliminate oscillations, implementing optimal hardware timer stepping.
    [SmartServoStepperV2.ino]
2026-05-16 Docs: Update README.md to v3.0.0 reflecting the new FastAccelStepper Direct Frequency architecture and updated PIN configurations
2026-05-17 docs: Update PCB wiring schematic to perfectly match .ino firmware pinout (STEP=4, DIR=2, SCL=10, Feetech Level Shifter)
2026-05-17 feat: Add KiCad schematic reference doc + fix swapped UART comments in config.h (1k on TX/GPIO6)
    [config.h]
2026-05-17 docs: Add HTML version of KiCad schematic reference
2026-05-17 docs: Add module-to-module wiring guide with point-to-point netlist (HTML)
2026-05-17 docs: Add Master-Schaltplan v2.2 with Dupont connectors J1/J2 and module-based layout
2026-05-17 docs: Add high-resolution KiCad schematic diagrams to Master-Schaltplan and HTML docs
2026-05-17 style: Update dashboard title to Good Time Robotics by Emil, Anton und Andreas Pfeiffer
2026-05-17 style: Restore Smart Servo Stepper to centered dashboard header title
2026-05-17 style: Keep SmartServo Stepper title on the left and place brand title centered in the middle
2026-05-18 Update hardware schematics, PCB layout, PDF exports, and review reports for V2
    [SmartServoStepperV2.kicad_pcb, SmartServoStepperV2.kicad_sch, SmartServoStepperV2_V2.kicad_pcb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]
2026-05-18 docs: Add IPC-2152 trace width calculations and KiCad Net Classes to master plan
2026-05-19 Add gerber files, manufacturing zip and KiCad board/schematic source files
    [SmartStepperServo-B_Cu.gbr, SmartStepperServo-B_Mask.gbr, SmartStepperServo-B_Paste.gbr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]
